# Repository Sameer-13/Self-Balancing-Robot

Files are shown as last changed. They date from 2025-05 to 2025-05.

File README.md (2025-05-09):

# Self-Balancing Robot

A two-wheeled robot that balances itself using PID control and an IMU sensor.

Self-Balancing Robot

## Overview

This project implements a self-balancing robot using an LPC1768 microcontroller that reads values from a Sparkfun 9DOF IMU and uses a PID control system to maintain balance. The robot uses an L298N motor driver to drive two DAGU DG01D motors powered by two 6V batteries connected in series.

## Components

- LPC1768 microcontroller
- Sparkfun 9DOF IMU sensor
- L298N motor driver
- 2 x DAGU DG01D motors
- 2 x 6V batteries (connected in series to provide 12V)
- 3D printed robot structure

## How It Works

### IMU (Inertial Measurement Unit)

The 9DOF IMU provides accelerometer and gyroscope readings in 3 axes (x, y, z). The system:
- Wakes up the IMU from sleep mode by writing to register 1
- Uses I2C communication protocol
- Has accelerometer and gyroscope scales of ±2g and ±250 deg/s respectively
- Uses two 10kΩ pull-up resistors on SDA and SSL inputs
- Calculates the tilt angle using the accelerometer readings

### Motor Control

The L298N motor driver:
- Controls two DC motors simultaneously
- Supplies approximately 8.5V to each motor (after 3.5V voltage drop)
- Uses PWM frequency of 25 kHz
- Controls motor states (FORWARD, BACKWARD, BRAKE, STOP) via control pins

### PID Controller

The Proportional-Integral-Derivative (PID) controller:
- Takes the tilt error as input and outputs motor control signals
- Runs at 300 Hz frequency (updates every 1/300 seconds)
- Uses tunable parameters Kp, Ki, and Kd for stability
- Includes a 5° tolerance zone for the STOP state
- Uses gyroscope readings directly for derivative calculations

## 3D Printing Design

3D Model

The 3D design files for the robot structure can be found at: [3D Print Files](https://makerworld.com/en/models/691734-fall-e-the-self-balancing-robot?from=search#profileId-620442)

*Note: The current design is quite heavy, which affects the robot's ability to balance against gravity's torque at higher angular accelerations. Consider using lighter materials or a redesigned structure for better performance.*

## Challenges Faced

1. Rapid PWM value changes during tuning caused overheating issues, burning two motor drivers
2. The initial 3d-printed structure was too heavy, limiting the robot's balancing capability
3. Replacing the burned motor driver required redesigning the robot to accommodate a larger driver and additional batteries

## Key Parameters

The project uses these key parameters for best performance:

- PID frequency: 300 Hz
- PWM frequency: 25 kHz
- Kp: 7.5
- Ki: 0.5
- Kd: 1.0
- ANGLE_TOLERANCE: 5° (±5° range for STOP state)

## Development Environment

The project was developed using:
- mbed library/RTOS
- Keil Cloud Studios (studio.keil.arm.com)
- API documentation: https://os.mbed.com/docs/mbed-os/v6.16/apis/index.html

## Running the Project on LPC1768 using Keil Studio

Follow these steps to run the project on your LPC1768 microcontroller:

1. Sign in to ARM Keil Studio (studio.keil.arm.com)
2. Create a new project
3. Connect the LPC1768 to your computer via USB
4. Choose "mbed LPC1768" in the "Build target" section in the side bar
5. Select your device in the "Connected device" section in the side bar
6. Install WEBUSB firmware if you haven't already:
   - Follow the steps in this link: https://forums.mbed.com/t/new-beta-firmware-for-lpc1768/18917
   - Note: Without this step, you will get a "USB access denied" error
7. Enable WebUSB from Keil Studio settings
8. Copy the C++ code into your project
9. Save the file
10. Build the project and save the .bin file directly to the LPC1768 device
11. Run the program
12. Choose the baud rate from the ">_" option (recommended: 9600)

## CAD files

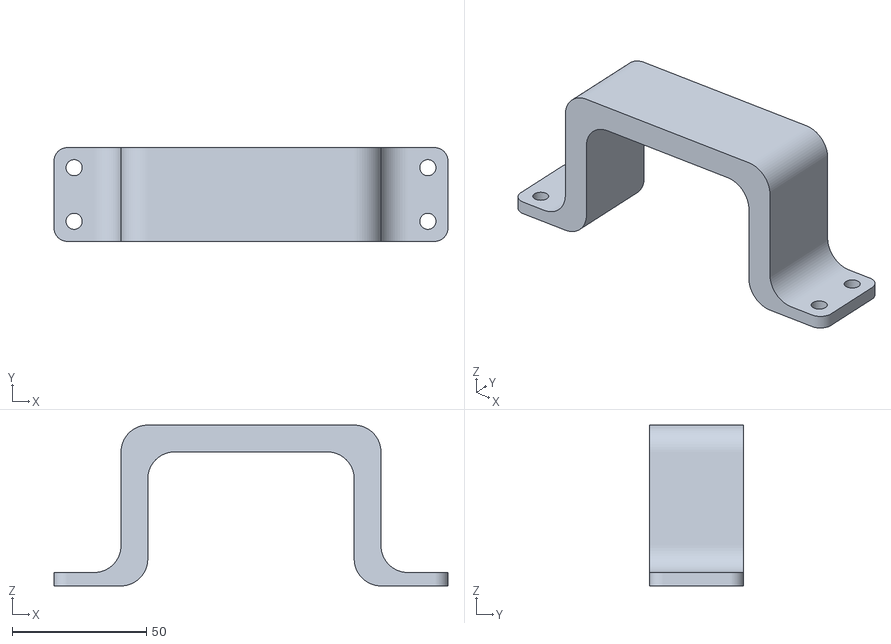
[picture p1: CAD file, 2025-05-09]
3D Components/handle.stl
147.0 x 35.0 x 60.0

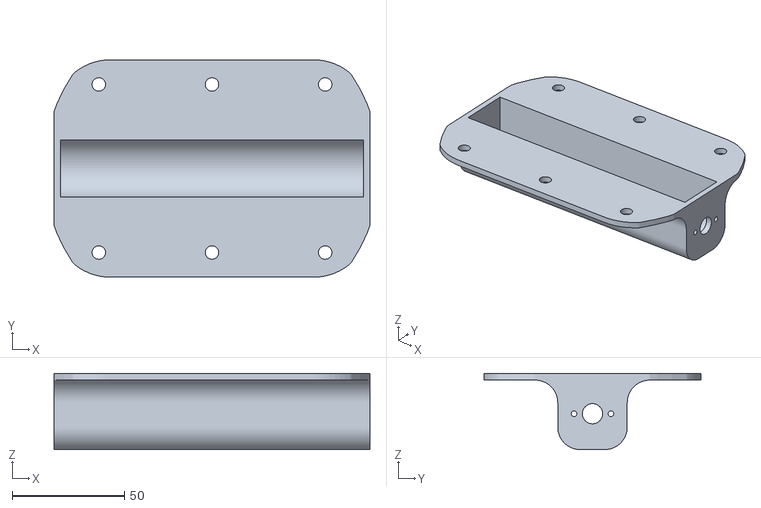
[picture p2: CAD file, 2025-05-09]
3D Components/motors_housing.stl
141.0 x 97.0 x 34.0

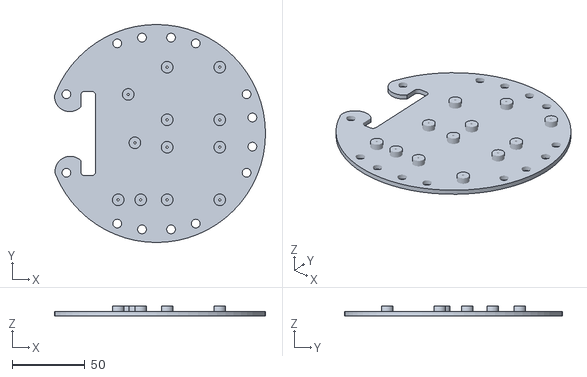
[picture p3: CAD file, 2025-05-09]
3D Components/plate_2.stl
145.2 x 150.0 x 7.00

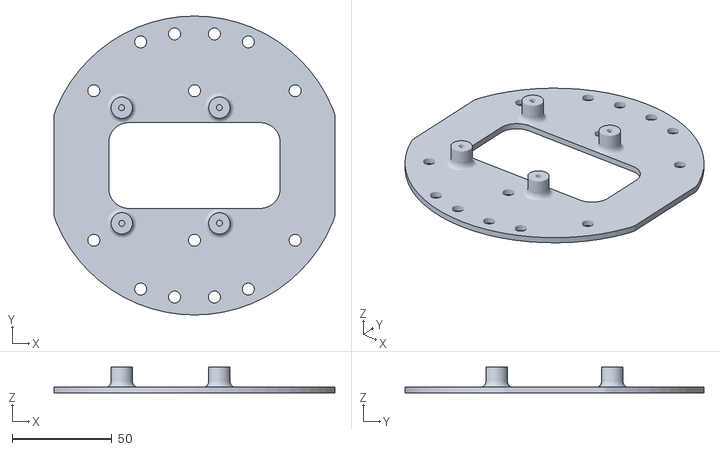
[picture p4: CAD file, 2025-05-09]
3D Components/raspi_baseplate.stl
141.0 x 150.0 x 13.0

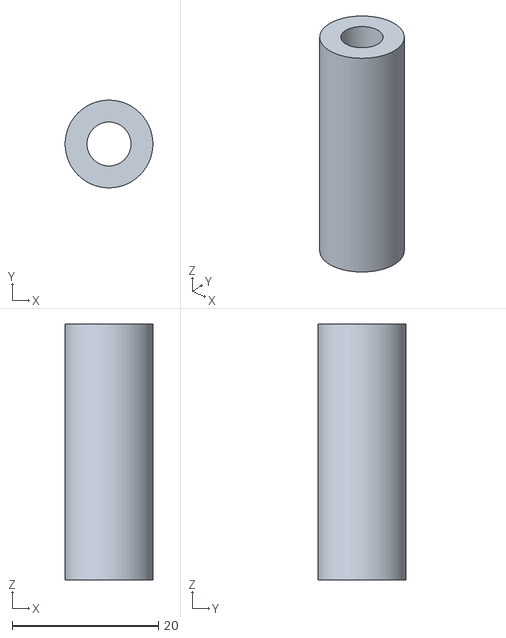
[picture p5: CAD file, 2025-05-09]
3D Components/spacer.stl
12.0 x 12.0 x 35.0

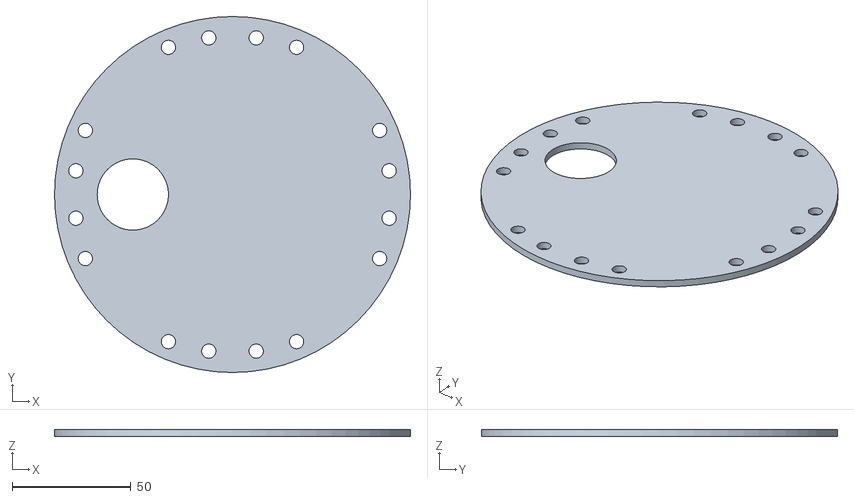
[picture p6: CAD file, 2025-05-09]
3D Components/plate_4.stl
150.0 x 150.0 x 3.00

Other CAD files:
3D Components/plate_3.stl

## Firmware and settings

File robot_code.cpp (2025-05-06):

#include "mbed.h"

#define PI 3.141592653589793
#define PID_FREQ 300
#define PID_PERIOD (1.0f / PID_FREQ)
#define IMU_I2C_ADDR 0X68
#define ACC_W 1.0f
#define GYRO_W 1.0f - ACC_W
#define ACC_ERROR  6.0f / 180.f //This is the error value we measured from the accelerometer and is a constant (6 degrees)
#define ANGLE_TOLERANCE 1.0f / 180.0f //2 degrees tolerance for stopping the motor
#define Kp 7.5f
#define Ki 0.0f
#define Kd 1.0f
#define ALPHA 0.25f // integral = (1 - ALPHA) * integral + ALPHA * error
#define PID_THRESH (PID_PERIOD / 0.1f)

enum motor_state
{
    FORWARD, BACKWARD, BRAKE, STOP
};


I2C imu_i2c(p9, p10);
DigitalOut myLed(LED1);
DigitalOut slave_sel(p14);

DigitalOut Ain1(p23);
DigitalOut Ain2(p22);
DigitalOut Bin1(p19);
DigitalOut Bin2(p18);
PwmOut     PWMA(p21);
PwmOut     PWMB(p24);

float X_GYRO_BIAS = 0;
float Y_GYRO_BIAS = 0;
float Z_GYRO_BIAS = 0;

EventQueue queue;
void updateFromPID(float, float);
void updateAngle(float, float, float, float);
Event<void(float, float)> pid(&queue, updateFromPID);
Event<void(float,float,float,float)> updateAngleEvent(&queue, updateAngle);


// main() runs in its own thread in the OS

void setup_pwm(PwmOut PWM, float duty_cycle, int period_micros)

{
    PWM.period_us(period_micros);
    PWM.write(duty_cycle);
}

void drive_motor(motor_state state)
{
    //forward -> IN1 = 0 , IN2 = 1;
    //backward -> IN1 = 1, IN2 = 0;
    //brake -> IN1 = 1, IN2 = 1;
    //stop -> IN1 = 0, IN2 = 0;

        switch(state)
        {
            case FORWARD:  Ain1 = 0; Ain2 =  1; Bin1 = 0; Bin2 = 1; break;
            case BACKWARD: Ain1 = 1; Ain2 = 0; Bin1 = 1; Bin2 = 0; break;
            case BRAKE: Ain1 = 1; Ain2 = 2; Bin1 = 1; Bin2 = 1; break;
            case STOP: Ain1 = 0; Ain2 = 0; Bin1 = 0; Bin2 = 0; break;
        }

   


}

void imu_wakeup()
{
    int power_addr = 0x6;
    char data[2] = { (char)power_addr, 0x01 }; // First: register address, Second: value to write
    int slave_addr = IMU_I2C_ADDR << 1;
    imu_i2c.write(slave_addr, data, 2);
}

int* imu_read(int start_addr) 
{
    char addr = (char) start_addr;

    imu_i2c.write(IMU_I2C_ADDR << 1, &addr, 1, true); // 'true' -> keep bus active (no stop)

    static int data[3];
    char raw_data[6];

    // Now read 6 bytes
    imu_i2c.read(IMU_I2C_ADDR << 1, raw_data, 6);

    int x_h = raw_data[0];
    int x_l = raw_data[1];
    int y_h = raw_data[2];
    int y_l = raw_data[3];
    int z_h = raw_data[4];
    int z_l = raw_data[5];

    data[0] = (x_h << 8 | x_l) << 16 >> 16; 
    data[1] = (y_h << 8 | y_l) << 16 >> 16; 
    data[2] = (z_h << 8 | z_l) << 16 >> 16; 

    return data;
}

float fast_sqrt(float x) {
    float guess = x / 2.0f;
    for (int i = 0; i < 3; i++) {
        guess = (guess + x / guess) / 2.0f;
    }
    return guess;
}

float fast_arccos(float x)
{
    //MAP OF ARCCOSINE VALUES FROM -1 TO 1 from indices [0, 300]
    static const float arccosMap[] = 
    {PI,
3.026058353305556,2.9781113472186513,2.9412578112666736,
2.910136241811168,2.882671111583572,2.857798544381465,
2.8348868812294103,2.8135247715438427,2.7934266323168324,
2.774384633031956,2.756241952455762,2.738876812009132,
2.7221924107679407,2.706110296865632,2.6905658417935308,
2.6755050556109614,2.6608822873372495,2.646658527248898,
2.6328001290794227,2.619277831783745,2.6060659992754056,
2.5931420215729823,2.580485837359395,2.5680795491666966,
2.555907110132642,2.5439540667066542,2.532207345558998,
2.520655075754206,2.5092864393102867,2.498091544796509,
2.487061319773459,2.4761874187533457,2.4654621440291318,
2.454878377240203,2.444429519947561,2.4341094418104503,
2.4239124352091883,2.4138331753608298,2.4038666851365442,
2.3940083039207725,2.384253659958957,2.3745986457279264,
2.365039395934791,2.3555722678095226,2.3461938234056494,
2.336900813664556,2.3276901640333034,2.318558961454817,
2.3095044425737288,2.300523983021863,2.291615087664986,
2.282775381707464,2.274002602564344,2.2652945924214523,
2.2566492914136074,2.2480647313592916,2.2395390299972684,
2.231070385676808,2.222657072458606,2.214297435588181,
2.205989887307672,2.1977329029755763,2.1895250174671474,
2.1813648218309956,2.173250960179887,2.165182126795959,
2.1571570634324884,2.1491745567961003,2.1412334361948187,
2.133332571338752,2.125470870281424,2.117647277490841,
2.1098607720403977,2.1021103659105753,2.0943951023931957,
2.0867140545906953,2.079066324003543,2.0714510391994847,
2.0638673545588304,2.056314449090488,2.048791525313849,
2.041297808202054,2.033832544182489,2.02639500019072,
2.018984462774328,2.0116002372434183,2.0042416468647826,
1.9969080320969432,1.9895987498634984,1.9823131728623846,
1.9750506889088353,1.9678107003099783,1.9605926232691573,
1.953395887318194,1.946219934775936,1.9390642202315367,
1.9319282100510304,1.9248113819058552,1.9177132243220583,
1.9106332362490184,1.9035709266465735,1.8965258140895267,
1.8894974263885678,1.8824853002266948,1.8754889808102941,
1.8685080215340726,1.8615419836590963,1.8545904360032244,
1.8476529546432756,1.8407291226283,1.8338185297033653,
1.8269207720432998,1.8200354519958641,1.8131621778338598,
1.8063005635156963,1.799450228453979,1.792610797291691,
1.7857818996855725,1.7789631700963175,1.7721542475852274,
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

    int index = (int) ((x + 1) * 150);
    return arccosMap[index];
}

float get_angle(float x_acc, float y_acc, float z_acc, float z_gyro)
{
    //acc_w and gyro_w are the weighted mean parameters, acc_w + gyro_w must be one
    //angle will be measured in RADIANS
    

    static float gyro_angle_prev = 0;
    
    float z_comp = z_acc < -1.0 ? -1.0 : z_acc > 1.0 ? 1.0 : z_acc; /// fast_sqrt(x_acc * x_acc + y_acc * y_acc + z_acc * z_acc);
    
    float acc_angle = fast_arccos(z_comp);

    //printf("Acc Angle: %d\n", (int) (acc_angle * 100));



    acc_angle = y_acc < 0 ? -acc_angle : acc_angle;

    
    // float gyro_angle = gyro_angle_prev + z_gyro * PI / 180 * PID_PERIOD;
    // gyro_angle_prev = gyro_angle;

    //printf("gyro angle: %d\n", (int) gyro_angle);
    //printf("acc angle: %d\n", (int) acc_angle);


    //return GYRO_W * gyro_angle + ACC_W * acc_angle;



    return acc_angle;

}

void updateAngle(float x_acc, float y_acc, float z_acc, float x_gyro)
{
    float new_angle = get_angle(x_acc, y_acc, z_acc, x_gyro);
    pid.post(new_angle, x_gyro);
}

void updateFromPID(float raw_angle_rad, float x_gyro) {


    float norm_angle = raw_angle_rad / PI;

    float error = -norm_angle;



    static float prev_error       = 0.0f;
    static float integral         = 0.0f;
    static float duty_cycle_prev       = 0.0f; 
    float mag = 0;
    //float delta_derivative  = (error - prev_error) * PID_FREQ;  
    float delta_e = error * PID_PERIOD;
    

    float derivative = x_gyro / 250;
    float theta_max = 30.0f;
    float abs_t = fabs(raw_angle_rad);  
    float scale = abs_t / theta_max;     
    if (scale > 1) scale = 1;

    float Kp_max = 1.0f / 0.524;
    float Kd_max = 0.15 * Kp_max;
    float Kp_eff = Kp + (Kp_max - Kp) * scale;
    float Kd_eff = Kd + (Kd_max - Kd) * scale;

    if (fabs(error) > ANGLE_TOLERANCE)
        integral = (1 - ALPHA) * integral + delta_e;

    float duty_cycle = Kp_eff * error
               + Ki * integral
               + Kd_eff * derivative;
    



    


    float delta = duty_cycle - duty_cycle_prev; 

    // clamp the change
    if      (delta >  PID_THRESH) delta =  PID_THRESH;  
    else if (delta < -PID_THRESH) delta = -PID_THRESH;

    duty_cycle_prev = duty_cycle;
    duty_cycle = duty_cycle_prev + delta;   


    if      (duty_cycle >  1.0f) duty_cycle =  1.0f;
    else if (duty_cycle < -1.0f) duty_cycle = -1.0f;


    mag = fabs(duty_cycle);

    if (fabs(norm_angle) < ANGLE_TOLERANCE) {
        drive_motor(STOP);
        duty_cycle = 0.0f;
        PWMA.write(0.0f);
        PWMB.write(0.0f);
        integral = 0.0f;
    } else {
        if (duty_cycle >= 0.0f) {
            drive_motor(FORWARD);
        } else {
            drive_motor(BACKWARD);
        }
        
        PWMA.write(mag);
        PWMB.write(mag);
    }

    

    prev_error = error;
}


int main()
{

    
    float duty_cycle = 0.45;
    int period_micros = 50; //20kHz
    setup_pwm(PWMA, duty_cycle, period_micros);
    setup_pwm(PWMB, duty_cycle, period_micros);
    motor_state init_state = FORWARD;
    drive_motor(init_state);


    int acc_addr = 45;
    int gyro_addr = 51;

    float ACCEL_SENS = 16384.0; // Sensitivity in LSB / g
    float GYRO_SENS = 131.0; // Sensitivity in LSB / (deg / s) 
    slave_sel.write(0); 

    int* data_read;
    float x_acc,y_acc,z_acc, x_gyro, y_gyro, z_gyro;
    myLed = 1;

    float curr_angle = 0;

    Thread pid_thread;


    Thread event_thread;
    event_thread.start(callback(&queue, &EventQueue::dispatch_forever));
    

    imu_wakeup();
    int CALIB_ITER = 500;

    for(int i = 0; i < CALIB_ITER; i++)
    {
        data_read = imu_read(gyro_addr);
        X_GYRO_BIAS += data_read[0] / GYRO_SENS;
        Y_GYRO_BIAS += data_read[1] / GYRO_SENS;
        Z_GYRO_BIAS += data_read[2] / GYRO_SENS;
    }

    X_GYRO_BIAS /= CALIB_ITER;
    Y_GYRO_BIAS /= CALIB_ITER;
    Z_GYRO_BIAS /= CALIB_ITER;

    while (true) {
            data_read = imu_read(acc_addr);
            x_acc = data_read[0] / ACCEL_SENS;
            y_acc = data_read[1] / ACCEL_SENS;
            z_acc = data_read[2] / ACCEL_SENS;
            
            data_read = imu_read(gyro_addr);
            x_gyro = data_read[0] / GYRO_SENS - X_GYRO_BIAS;
            y_gyro = data_read[1] / GYRO_SENS - Y_GYRO_BIAS;
            z_gyro = data_read[2] / GYRO_SENS - Z_GYRO_BIAS;

            // printf(
            //     "GYRO (X, Y, Z): %d, %d, %d\n",
            //     (int) x_gyro, (int) y_gyro, (int) z_gyro
            // );
            // fflush(stdout);

            updateAngleEvent.post(x_acc, y_acc, z_acc, x_gyro);
            ThisThread::sleep_for(chrono::milliseconds((int)(PID_PERIOD * 1000)));


    }
}

 
